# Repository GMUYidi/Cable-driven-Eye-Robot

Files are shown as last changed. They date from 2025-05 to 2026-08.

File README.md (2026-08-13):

# Cable-Driven Eye Robot

Robotic-eye platform for human vision visualization, binocular gaze control,
strabismus simulation, and saccade/foveation experiments.

This repository contains hardware design files, control software, calibration
data, experiment scripts, videos, and analysis tools for a two-eye cable-driven
robotic platform. The current engineering direction is to organize the project
as a full robotics system: hardware, sensing, actuation, kinematics, calibration,
control, telemetry, and visual perception.

## Project Goal

The platform is designed to visualize what a moving eye sees during human-like
eye motion. In particular, the project focuses on:

- Cable-driven robotic eye actuation with 12 Dynamixel motors.
- Binocular yaw, pitch, and torsional eye motion.
- Open-loop inverse-kinematic control from desired gaze angle to motor command.
- IMU-based feedback and pose measurement.
- Dual camera streaming from the eye viewpoint.
- Camera and eye-pose calibration.
- Saccade, fixation, and foveated-perception visualization.
- Data collection for human vision visualization and strabismus diagnosis.

The long-term system objective is:

> From a high-level gaze or saccade command, generate coordinated two-eye motor
> motion, measure the actual eye pose, capture the visual scene from the eye's
> viewpoint, and render what the eye sees during fixation and saccadic motion.

## System Architecture

The project is organized around a layered robotics architecture:

```text
Experiment protocol
  -> gaze target or saccade command
  -> binocular motion planner
  -> eye kinematics and calibration
  -> Dynamixel motor command generation
  -> physical cable-driven eye motion
  -> IMU and camera feedback
  -> synchronized telemetry
  -> foveated visualization and analysis
```

See [ARCHITECTURE.md](ARCHITECTURE.md) for the full architecture document.

## Demo Programs

The runnable demos are thin entry points in [`demos`](demos). They call reusable
modules from [`src/cable_driven_eye_robot`](src/cable_driven_eye_robot), so the
hardware drivers, kinematics, control loops, sensors, and UI are not duplicated
inside large one-file scripts.

```bash
python demos/dashboard_demo.py
python demos/initial_position_tuner.py
python demos/feedback_control.py
python demos/hess_chart_tracking.py
python demos/eye_tracker_replay.py --data-path experiments/eye_tracking/processed_data/<file>.mat
```

- `dashboard_demo.py`: joystick open-loop control, dual IMU pose display, and
  dual ESP32 camera streaming.
- `initial_position_tuner.py`: manual neutral-position calibration for all 12
  Dynamixel motors.
- `feedback_control.py`: joystick target plus IMU feedback correction and CSV
  telemetry logging.
- `hess_chart_tracking.py`: generate Hess-chart gaze targets, track each point
  with IMU feedback, then capture synchronized eye-camera frames when the pose
  reaches tolerance.
- `eye_tracker_replay.py`: replay recorded eye-tracker gaze targets with
  open-loop inverse kinematics and capture synchronized eye-camera frames.

## Repository Structure

```text
.
|-- README.md
|-- ARCHITECTURE.md
|-- requirements.txt
|-- demos/
|   |-- dashboard_demo.py
|   |-- initial_position_tuner.py
|   |-- feedback_control.py
|   |-- hess_chart_tracking.py
|   `-- eye_tracker_replay.py
|-- src/
|   `-- cable_driven_eye_robot/
|       |-- apps/
|       |-- control/
|       |-- data/
|       |-- hardware/
|       |-- input_devices/
|       |-- sensors/
|       |-- ui/
|       |-- config.py
|       `-- kinematics.py
|-- docs/
|   |-- DEMO_RUNBOOK.md
|   |-- HARDWARE.md
|   |-- BILL_OF_MATERIALS.md
|   |-- WIRING.md
|   |-- SOFTWARE_ARCHITECTURE.md
|   |-- CONTROL_AND_CALIBRATION.md
|   |-- REPOSITORY_STRUCTURE.md
|   `-- FILES_NEEDED.md
|-- firmware/
|   `-- esp32_imu_camera/
|-- calibration/
|   `-- camera_intrinsics/
|-- hardware/
|   `-- cad/
|-- experiments/
|   |-- open_loop_accuracy/
|   |-- eye_tracking/
|   `-- binocular_visualization/
|-- media/
|   `-- videos/
`-- tools/
    `-- fusion360/
```

The top-level folders are grouped by responsibility. `src` and `demos` are the
runtime software, `hardware` and `firmware` describe the physical system,
`calibration` stores reusable calibration artifacts, `experiments` stores
research datasets and analysis outputs, `media` stores videos, and `tools`
stores project maintenance scripts.

Representative binocular visualization outputs are included under
[`experiments/binocular_visualization/hess_matched_results`](experiments/binocular_visualization/hess_matched_results).
This result set contains Hess-matched strabismus simulation videos, a healthy
binocular reference video, and the reports/metadata/matrix files needed to
trace each generated video.

## Hardware Summary

- 2 cable-driven robotic eyes.
- 12 ROBOTIS Dynamixel XL330-M288-T actuators, 6 per eye.
- Dynamixel Protocol 2.0 over USB serial.
- ROBOTIS U2D2 and U2D2 Power Hub Board.
- Servo power is injected through the U2D2 Power Hub Board; the currently
  reported adapter is 12 V / 5 A, but the XL330-M288-T bus voltage must be
  verified or regulated before operation.
- Adafruit BNO055 IMU sensing for eye orientation.
- ESP32-S3-CAM OV3660 modules for eye-view video streaming.
- Joystick input for manual gaze control.
- Fusion 360 mechanical design files and exported STL parts.

See [docs/HARDWARE.md](docs/HARDWARE.md),
[docs/BILL_OF_MATERIALS.md](docs/BILL_OF_MATERIALS.md), and
[docs/WIRING.md](docs/WIRING.md) for more detail.

## Software Summary

The control software currently supports:

- Dynamixel sync-write of goal positions.
- Dynamixel sync-read of present positions.
- Extended Position Mode.
- Joystick input through `pygame`.
- Inverse-kinematic cable/muscle pulse computation.
- Listing-law-inspired torsional roll computation.
- IMU serial parsing.
- ESP32 camera stream display through OpenCV.
- CSV logging and offline visualization scripts.

See [docs/CONTROL_AND_CALIBRATION.md](docs/CONTROL_AND_CALIBRATION.md) for the
control and calibration model, and
[docs/SOFTWARE_ARCHITECTURE.md](docs/SOFTWARE_ARCHITECTURE.md) for the modular
software layout.

## Quick Start

Install the Python dependencies:

```bash
pip install -r requirements.txt
```

Run the integrated joystick, IMU, and camera dashboard:

```bash
python demos/dashboard_demo.py
```

Tune the neutral motor positions:

```bash
python demos/initial_position_tuner.py
```

Run the IMU feedback-control demo:

```bash
python demos/feedback_control.py
```

For detailed hardware setup, port configuration, and safety checks, see
[docs/DEMO_RUNBOOK.md](docs/DEMO_RUNBOOK.md).

## Engineering Status

This repository currently contains both research artifacts used to produce
experimental results and a modular runtime for the current robotic-eye demos.

The current refactor direction is to separate:

- Experiment protocols.
- Gaze target generation.
- Saccade and fixation planning.
- Binocular coordination.
- Eye kinematics.
- Dynamixel transport.
- IMU and camera sensing.
- Calibration loading.
- Telemetry logging.
- Foveated visualization.

## Citation / Research Context

This project supports the research work:

**A Novel Cable-driven Eye Robot for Human Vision Visualization and Strabismus
Diagnosis**

The repository includes control code, hardware design files, eye-tracking data,
strabismus simulation resources, and videos related to that work.

## Contact

Yidi Huang
George Mason University
Email: yhuang35@gmu.edu

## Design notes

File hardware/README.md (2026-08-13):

# Hardware

This folder stores hardware design resources for the cable-driven eye robot.

```text
hardware/
  cad/
    fusion360_stl/   exported mechanical parts for fabrication
```

The mechanical design is separated from software so the repository can be read
as a complete robotics system: hardware, firmware, calibration, control, and
experiments.

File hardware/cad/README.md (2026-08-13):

# CAD

Mechanical design files and exported fabrication assets.

```text
hardware/cad/
  fusion360_source/   Fusion 360 source archives, such as .f3d or .f3z
  step/               editable CAD exchange files for solid parts
  stl/                3D-printable mesh exports
  export_inbox/       temporary manual export drop folder
```

For each printable solid part, publish both `.step` and `.stl` when possible.
Mesh-only face-cover parts can be published as `.stl` unless they are converted
to solid BRep bodies in Fusion 360.

See `EXPORT_MANIFEST.md` for the exact printable parts list.

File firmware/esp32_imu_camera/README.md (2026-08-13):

# ESP32 IMU Camera Firmware

This folder contains firmware for the ESP32-S3 camera and BNO055 IMU module.

Main firmware:

```text
IMUcamera.ino
```

The firmware is responsible for:

- Starting the ESP32 camera stream.
- Reading BNO055 IMU data.
- Sending IMU orientation data over serial.
- Joining or creating a Wi-Fi network for camera streaming.

Local Wi-Fi credentials should be stored in `wifi_secrets.h`. That file is
ignored by git and should not be committed.

An example credentials file can be created locally as:

```c
#define WIFI_SSID "your-network"
#define WIFI_PASSWORD "your-password"
```

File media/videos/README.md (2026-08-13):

# Videos

Video assets are grouped by purpose.

```text
videos/
  experiment_videos/              calibration and robot experiment recordings
  simulated_binocular_vision/     synthesized binocular-view videos
  simulated_monocular_vision/     synthesized monocular-view videos
  video_processing/               notebooks and scripts for video generation
```

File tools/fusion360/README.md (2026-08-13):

# Fusion 360 Export Tools

This folder contains helper scripts for exporting selected parts from the
Fusion 360 design.

## Export Workflow

1. Open `headlike robotic eye` in Fusion 360.
2. Save a full source archive manually:
   - `File > Export > Fusion 360 Archive (*.f3z)`
   - Save as `hardware/cad/fusion360_source/headlike_robotic_eye_assembly.f3z`.
3. In Fusion 360, open:
   - `Utilities > Scripts and Add-Ins`.
4. Create or add a Python script and copy the contents of
   `export_headlike_robotic_eye_parts.py`.
5. Run the script while the design is open.
6. Check the generated files in:
   - `hardware/cad/step/`
   - `hardware/cad/stl/`

If a mesh face-cover body cannot be exported by the script, manually right-click
that mesh body and export it as STL using the filenames in
`hardware/cad/EXPORT_MANIFEST.md`.

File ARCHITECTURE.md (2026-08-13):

# Robotic Eye Architecture

## Overview

This project is a robotic-eye control and visualization platform for studying how
the visual scene changes during human-like eye motion. The central goal is not
only to move two artificial eyes, but to make the relationship between gaze,
saccades, fixation, camera input, and foveated perception visible and measurable.

The system should be understood as a layered robotics architecture:

```text
Experiment intent
  -> gaze target / saccade command
  -> binocular eye-motion planner
  -> eye kinematics and calibration
  -> motor command generation
  -> Dynamixel actuator transport
  -> physical eye motion
  -> IMU + camera feedback
  -> synchronized visualization and analysis
```

Current code already contains the main building blocks: joystick-driven gaze
commands, kinematic mapping from yaw/pitch/roll to cable or muscle pulses,
Dynamixel sync-write control, IMU feedback, ESP32 camera streaming, logging, and
offline plotting. This document makes those responsibilities explicit and defines
the architecture needed to support the next research goal: visualizing saccade
and foveation motion from the eye's own viewpoint.

## 1. System Goal

The system goal is to visualize what a moving eye "sees" during saccades and
fixations.

More specifically, the platform should:

- Reproduce gaze shifts that approximate human eye behavior, including fixation,
  fast saccadic motion, post-saccadic settling, and optional pursuit-like motion.
- Capture the camera view from each eye during those movements.
- Estimate the actual eye pose over time from IMU feedback and motor telemetry.
- Show how the scene moves across the image plane during a saccade.
- Provide a foveated view: high-detail information around the gaze center and
  lower-detail peripheral context around it.
- Log commands, measured motion, camera frames, and timing so that each run can
  be replayed, analyzed, and compared.

The research question can be stated as:

> When the robotic eye performs human-like gaze shifts, how does the visual input
> change over time, and how can that change be visualized as foveated perception?

This is different from a simple eye-motion demo. A simple demo asks, "Can the eye
move to a target?" This project asks, "What visual information is available
during that movement, and how does the system represent the difference between
fixation, saccade, and post-saccadic stabilization?"

### Design Priorities

- The visual output matters as much as the mechanical motion.
- The command path and sensing path must be synchronized.
- Gaze trajectories should be repeatable, not only manually controlled.
- Calibration must connect four spaces: motor ticks, eye pose, camera pixels,
  and visual/foveal coordinates.
- The architecture should support both online control and offline replay.

### Non-Goals

- The current system does not need to be a perfect biological model of the human
  retina, eye muscles, or neural control.
- The first version does not need a real-time neural vision model.
- The first version does not need perfect high-speed saccades if the camera,
  IMU, and motor rates limit the measurable bandwidth.

The correct first milestone is a synchronized, measurable, and visually clear
approximation of saccade/fixation/foveation behavior.

## 2. Hardware Overview

The physical platform is a binocular robotic-eye rig with two mechanically
actuated eyes.

### Robotic Eyes

- Two eyes: left and right.
- Each eye is controlled by six actuator channels that approximate extraocular
  muscle actions.
- The modeled muscle order is:
  - MR: medial rectus
  - LR: lateral rectus
  - SR: superior rectus
  - IR: inferior rectus
  - SO: superior oblique
  - IO: inferior oblique
- The eye geometry in the modular controller uses an eyeball radius of 15 mm.
- The kinematic layer converts desired yaw, pitch, and roll into actuator pulse
  differences using insertion points, pulley points, pulse scales, and offsets.

### Actuators

- The current controller targets 12 ROBOTIS Dynamixel XL330-M288-T servos, IDs
  1 through 12.
- IDs 1-6 correspond to the left eye; IDs 7-12 correspond to the right eye.
- Left eye IDs 1-6 map to LR, MR, SR, IR, SO, IO.
- Right eye IDs 7-12 map to MR, LR, SR, IR, SO, IO.
- The controller uses Dynamixel Protocol 2.0 at 1 Mbps.
- The default motor bus is configured as `COM12`.
- Motors are controlled in Extended Position Mode.
- Current code uses sync read for present position and sync write for goal
  position.
- Existing analysis scripts also read present current for estimating torque or
  cable force.
- The current reported power path is an external adapter feeding a U2D2 Power
  Hub Board, while the U2D2 provides USB-to-Dynamixel communication. The adapter
  was reported as 12 V / 5 A, but the actual XL330 bus voltage must be verified
  or regulated before operation.

### Sensors

- IMUs are used to estimate actual eye orientation.
- The IMU model is the Adafruit 9-DOF Absolute Orientation IMU Fusion Breakout -
  BNO055.
- The left IMU is currently mapped to `COM11`.
- The right IMU is currently mapped to `COM6`.
- IMU serial baud rate is 921600.
- The ESP32-S3 camera/IMU firmware uses a BNO055 IMU and currently emits IMU
  data at 20 Hz.

### Cameras

- Each eye can stream from an ESP32-S3-CAM Development Board with an OV3660
  camera, antenna, ESP32-S3 N16R8 module, 16 MB flash, and 8 MB PSRAM.
- Current default camera URLs are:
  - Left camera: `http://192.168.4.1/stream`
  - Right camera: `http://192.168.4.200/stream`
- Camera calibration files are stored under `calibration/camera_intrinsics/`.
- Camera intrinsics and distortion parameters are stored in `.npz` files.

### User Input and Host

- A joystick can provide manual target yaw/pitch commands.
- The host computer runs Python control scripts on Windows.
- Existing scripts use `pygame`, `dynamixel_sdk`, `serial`, `opencv-python`,
  `numpy`, `pandas`, `matplotlib`, `PIL`, and `tkinter`.

### Data Products

- Experiment datasets and analysis outputs are stored under `experiments/`.
- Generated videos are stored under `media/videos/`.
- Reusable calibration artifacts are stored under `calibration/`.

## 3. Software Architecture

The software should be organized around responsibility boundaries, not around
individual experiments. Each layer should have a clear input and output.

```mermaid
flowchart TD
    A["Experiment Protocol"] --> B["Gaze Target Source"]
    B --> C["Saccade and Fixation Planner"]
    C --> D["Binocular Coordination"]
    D --> E["Eye Kinematics"]
    E --> F["Motor Command Builder"]
    F --> G["Dynamixel Transport"]
    G --> H["Physical Robotic Eyes"]
    H --> I["IMU Feedback"]
    H --> J["Eye Cameras"]
    I --> K["Telemetry Logger"]
    J --> K
    F --> K
    K --> L["Replay and Analysis"]
    K --> M["Foveated Visualization"]
```

### Current Implementation Mapping

| Responsibility | Current Files |
| --- | --- |
| Demo entry points | `demos/` |
| Hardware constants and safety limits | `src/cable_driven_eye_robot/config.py` |
| Eye geometry and pulse computation | `src/cable_driven_eye_robot/kinematics.py` |
| Dynamixel sync read/write | `src/cable_driven_eye_robot/hardware/dynamixel.py` |
| Joystick input | `src/cable_driven_eye_robot/input_devices/joystick.py` |
| Shared math helpers | `src/cable_driven_eye_robot/math_utils.py` |
| Combined joystick, IMU, camera dashboard | `src/cable_driven_eye_robot/apps/dashboard_demo.py` |
| IMU feedback control | `src/cable_driven_eye_robot/control/feedback.py` |
| Open-loop control | `src/cable_driven_eye_robot/control/open_loop.py` |
| Camera calibration | `calibration/camera_intrinsics/` |
| ESP32 camera and IMU firmware | `firmware/esp32_imu_camera/IMUcamera.ino` |
| Binocular visualization outputs | `experiments/binocular_visualization/` |
| Offline videos and video processing | `media/videos/` |

### Recommended Target Architecture

The next refactor should separate the project into these conceptual modules:

- `experiment_protocols`: defines repeatable trials such as fixation, single
  saccade, multi-step scan path, pursuit, and replay.
- `gaze_sources`: joystick, scripted target sequence, recorded replay, visual
  target detector, or manual UI.
- `saccade_profiles`: converts target jumps into time-indexed gaze trajectories.
- `binocular_planner`: maps a desired gaze target into left-eye and right-eye
  target poses.
- `eye_kinematics`: converts eye pose into actuator pulse differences.
- `hardware`: owns Dynamixel transport, motor state, torque enable/disable, and
  reset.
- `sensors`: owns IMU readers, camera readers, timestamps, connection status,
  and calibration.
- `foveation`: converts gaze pose and camera frames into foveated visual output.
- `telemetry`: defines the logged data schema and writes synchronized CSV/video
  records.
- `visualization`: live dashboard, offline replay, plots, and presentation
  videos.

This separation matters because the same low-level eye controller should be
usable from a joystick, a scripted saccade experiment, a face/target tracker, or
an offline replay without rewriting motor code.

## 4. Data / Control Flow

The architecture has two important flows: the online control flow and the
offline analysis flow.

### Online Control Flow

```text
Target source
  -> desired gaze target
  -> saccade/fixation planner
  -> desired left/right eye pose
  -> yaw/pitch/roll with Listing roll
  -> muscle pulse differences
  -> absolute Dynamixel goal positions
  -> sync-write motor command
  -> physical eye motion
  -> IMU pose + camera frame + motor telemetry
  -> synchronized display and log
```

For joystick control, the target source is the joystick. For saccade
visualization, the target source should usually be a scripted experiment because
the motion must be repeatable.

### Offline Analysis Flow

```text
CSV telemetry + recorded camera/video
  -> timestamp alignment
  -> command vs actual pose comparison
  -> image-plane motion analysis
  -> foveated render generation
  -> plots, videos, and metrics
```

The offline path is important because camera, IMU, and motor data may run at
different rates. A replay pipeline can interpolate pose and align it with camera
frames more cleanly than the live dashboard can.

### Core Data Contracts

The system should converge around a small set of data types:

#### `GazeTarget`

Represents the high-level visual target.

```text
time_s
target_id
yaw_deg
pitch_deg
vergence_deg, optional
mode: fixation | saccade | pursuit | replay | manual
```

#### `EyePose`

Represents desired or measured eye orientation.

```text
time_s
side: left | right
yaw_deg
pitch_deg
roll_deg
source: command | imu | estimate
valid
```

#### `MotorCommand`

Represents the command sent to the actuator layer.

```text
time_s
motor_id
goal_position_ticks
goal_velocity, optional
goal_current, optional
profile_velocity
profile_acceleration
```

#### `FrameSample`

Represents a camera frame and its timing metadata.

```text
time_s
side: left | right
frame_index
image_width
image_height
camera_url
calibration_id
```

#### `TelemetrySample`

Represents one synchronized row for analysis.

```text
time_s
commanded_left_pose
commanded_right_pose
actual_left_pose
actual_right_pose
motor_positions
motor_currents
camera_frame_indices
experiment_stage
```

The current CSV files already contain many of these fields. The architectural
improvement is to make the schema intentional and consistent across experiments.

## 5. Module Responsibilities

### Experiment Layer

Responsible for deciding what the eye should do.

Examples:

- Hold center fixation for 1 s.
- Saccade 15 deg right in 150 ms.
- Hold fixation after the saccade for 1 s.
- Repeat the same command for five trials.
- Play a predefined scan path over a static scene.

This layer should not know about motor ticks, COM ports, or pulley geometry.

### Gaze Planner

Responsible for turning intent into a time-indexed gaze trajectory.

For saccades, this module should define:

- Start pose.
- End pose.
- Amplitude.
- Duration.
- Peak velocity.
- Acceleration and deceleration shape.
- Optional post-saccadic correction.
- Fixation duration before and after the movement.

The first implementation can use simple profiles such as minimum-jerk,
trapezoidal velocity, or a hand-tuned smooth step. Later versions can implement
human main-sequence-inspired relationships between amplitude, duration, and peak
velocity.

### Binocular Coordination

Responsible for producing left-eye and right-eye pose targets.

For most current experiments, both eyes can receive the same yaw/pitch target.
For more realistic visual behavior, this layer should support:

- Conjugate gaze: both eyes rotate in the same direction.
- Vergence: eyes rotate inward or outward for near/far targets.
- Per-eye calibration offsets.
- Per-eye motion limits.
- Optional suppression of one eye during monocular tests.

### Kinematics Layer

Responsible for mapping eye pose to actuator pulse differences.

Current implementation:

- `compute_listing_roll(x_deg, y_deg)` estimates roll from yaw/pitch.
- `compute_muscle_pulses(...)` rotates insertion points and computes muscle
  length changes relative to pulley points.
- Left and right geometries are built separately because the oblique muscles and
  sign conventions differ between eyes.

This layer should stay independent from Dynamixel transport. Its input should be
eye pose in degrees. Its output should be actuator deltas in ticks or normalized
muscle-length units.

### Actuator / Hardware Layer

Responsible for all Dynamixel communication and motor safety.

Current responsibilities include:

- Open/close the Dynamixel serial port.
- Set Extended Position Mode.
- Configure profile velocity and acceleration.
- Enable or disable torque.
- Sync-read present position.
- Sync-write goal position.
- Reset to calibrated perfect positions.
- Limit large jumps using `max_goal_step`.
- Unwrap multi-turn position targets near the previous goal.

No high-level experiment logic should live in this layer.

### Sensor Layer

Responsible for acquiring measured state.

IMU responsibilities:

- Open the left and right serial ports.
- Parse yaw, pitch, roll, angular velocity, angular acceleration, gyro, and
  linear acceleration when available.
- Apply zero calibration.
- Report connection status and sample age.

Camera responsibilities:

- Open left and right camera streams.
- Decode frames.
- Timestamp each frame.
- Apply camera intrinsics and distortion correction when needed.
- Report frame rate, dropped frames, and connection status.

### Foveation Layer

Responsible for converting camera frames and gaze state into a visualization of
foveated perception.

Initial foveation features:

- Mark the estimated gaze center in the camera image.
- Crop a high-resolution foveal window around the gaze center.
- Blur or downsample peripheral regions.
- Show the image-plane motion path during the saccade.
- Show before-saccade, during-saccade, and after-saccade frames side by side.

More advanced foveation features:

- Gaze-contingent resolution falloff.
- Motion blur or suppression during fast saccade phases.
- Stereo comparison between left and right eye views.
- Stabilized world view reconstructed from eye pose and camera frames.

### Telemetry and Logging Layer

Responsible for making experiments repeatable and analyzable.

Each run should log:

- Experiment name and trial number.
- Commanded gaze target.
- Active trajectory target at each timestep.
- Commanded left/right eye pose.
- Measured left/right IMU pose.
- Pose error.
- Motor goal positions.
- Motor present positions.
- Motor current, when available.
- Camera frame index or video timestamp.
- Loop timing and sensor ages.
- Safety events, resets, and dropped samples.

Logs should be written in a stable schema so that plotting scripts do not need
custom parsing for every experiment.

### Visualization Layer

Responsible for communicating the system behavior.

Live dashboard:

- Show commanded gaze.
- Show measured eye pose.
- Show left/right camera streams.
- Show connection health.
- Show recent errors and safety events.

Offline visualization:

- Plot target vs actual gaze.
- Plot yaw/pitch/roll error.
- Plot saccade duration, overshoot, and settling time.
- Render synchronized camera videos with gaze overlays.
- Render foveated videos showing high-detail center and low-detail periphery.

## 6. Timing and Control Loop

The project has multiple clocks:

- Motor command loop.
- IMU serial sampling.
- Camera frame sampling.
- Joystick polling.
- Visualization refresh.
- CSV/video logging.

These clocks should be treated separately and synchronized through timestamps.

### Current Timing

Existing code shows several timing regimes:

- The modular joystick loop sleeps for 0.002 s, which implies a target loop rate
  up to roughly 500 Hz if communication and computation allow it.
- Some feedback experiments use a 0.05 s loop period, or roughly 20 Hz.
- The ESP32 camera/IMU firmware sets the IMU interval to 50 ms, or 20 Hz.
- Dynamixel transport runs at 1 Mbps.
- Joystick command step limits are currently around 0.08 deg per loop for yaw
  and 0.06 deg per loop for pitch in the modular controller.

### Target Timing Architecture

The control loop should be designed as:

```text
high-rate motor command loop:
    consume latest desired trajectory pose
    compute motor goals
    write goals
    read available motor telemetry
    timestamp command and response

sensor loops:
    read IMU and camera at their own rates
    timestamp each sample immediately
    publish latest valid sample

visualization/logging loop:
    collect latest command, sensor, and frame samples
    align by timestamp
    display and write to disk
```

The motor command loop should not block on camera frame decoding. Camera frame
processing can be slower and asynchronous because foveation visualization is
allowed to lag slightly behind motor control.

### Saccade Trial Phases

A repeatable saccade experiment should use explicit stages:

1. `pre_fixation`: hold the start pose and collect baseline frames.
2. `saccade`: execute the planned rapid gaze transition.
3. `post_fixation`: hold the final pose and measure settling.
4. `return`: optionally return to center or the next start pose.
5. `complete`: stop motion, save logs, and render summary outputs.

Each logged row should include the current stage. This makes plots and videos
much easier to interpret.

### Latency Considerations

The key latency measurements are:

- Command generation to Dynamixel sync-write.
- Sync-write to measured IMU response.
- Camera exposure/readout to host timestamp.
- Camera frame timestamp to visualization display.
- Difference between commanded gaze center and displayed foveal center.

For the foveation goal, camera/pose synchronization is as important as raw motor
speed. A visually impressive demo can still be scientifically weak if the gaze
overlay and camera frame are not time-aligned.

## 7. Calibration Strategy

Calibration is the bridge between hardware motion and meaningful visual output.
The project needs calibration at several levels.

### Motor Zero / Perfect Position Calibration

Purpose:

- Define a repeatable neutral eye pose.
- Make motor commands relative to a known baseline.

Current implementation:

- `perfect_positions` are stored in configuration or experiment scripts.
- `reset_perfect()` sync-writes all motors to calibrated positions.
- The controller then reads present positions and updates the baseline.

Required improvement:

- Store each calibration as a named file with date, rig version, motor IDs, and
  notes.
- Avoid hard-coding different perfect positions across many experiment scripts.
- Record which calibration was used in every CSV log.

### Eye Geometry Calibration

Purpose:

- Map desired yaw/pitch/roll into actuator pulse changes.

Current implementation:

- Geometry is defined by insertion points, pulley points, pulse scales, and
  offsets in `kinematics.py`.

Required improvement:

- Fit pulse scales and offsets from measured motion data.
- Validate the model across a grid of commanded gaze targets.
- Store left and right eye geometry separately.
- Report expected vs measured yaw/pitch/roll error.

### IMU Calibration

Purpose:

- Convert raw IMU orientation into eye pose relative to the neutral pose.

Current implementation:

- Scripts zero IMU pose at startup or on command.
- Some scripts correct roll/camera zero offsets through helper functions.

Required improvement:

- Define a standard IMU coordinate convention.
- Record zero offsets in metadata.
- Track sample age and reject stale IMU data.
- Validate IMU pose against known commanded poses.

### Camera Intrinsic Calibration

Purpose:

- Correct lens distortion and make pixel measurements meaningful.

Current implementation:

- Checkerboard calibration scripts store camera matrix and distortion
  coefficients as `.npz` files.

Required improvement:

- Maintain separate calibration files for left and right cameras.
- Record image resolution and camera module identity.
- Apply undistortion before measuring pixel motion or foveal coordinates.

### Pixel-to-Gaze Calibration

Purpose:

- Map eye pose to image location.
- Identify where the foveal center should appear in each camera frame.

Required approach:

- Command the eye to a grid of yaw/pitch targets.
- Capture camera frames at each target.
- Detect a known visual marker or calibration target.
- Fit a mapping from `(yaw_deg, pitch_deg)` to `(u_px, v_px)`.
- Validate the mapping with held-out target points.

This calibration is essential for foveation. Without it, the system can show a
camera image, but it cannot confidently say where the gaze center is in that
image.

### Temporal Calibration

Purpose:

- Align motor commands, IMU samples, and camera frames.

Required approach:

- Timestamp commands and sensor samples with a common host clock.
- Estimate fixed camera delay if necessary.
- Use step or saccade events to align command onset with measured motion onset.
- Store measured delay values in the experiment metadata.

## 8. Safety Constraints

The system must protect both the hardware and the data quality.

### Motion Limits

Current limits include:

- Maximum yaw/pitch limits for joystick control.
- Deadband around joystick zero.
- Step limits for joystick command changes.
- Maximum pulse magnitude safety check.
- Maximum motor goal step in ticks.

These limits should remain active in all control modes, including scripted
saccades and replay.

### Torque and Reset Safety

The actuator layer should always support:

- Torque enable/disable.
- Reset to perfect positions.
- Reset to initial positions.
- Keyboard stop.
- Shutdown reset and torque disable.

If an exception occurs, the system should attempt to return to a safe state and
disable torque.

### Sensor Health

The system should detect:

- Missing IMU samples.
- Stale IMU data.
- Camera stream disconnects.
- Dropped camera frames.
- Dynamixel communication failures.
- Motor present position unavailable.

Safety behavior should be explicit. For example, if IMU feedback is stale during
a feedback-control trial, the controller should either hold the last safe command
or switch to open-loop mode with a logged warning.

### Mechanical Safety

Because the eyes are cable/muscle-like mechanisms, safety should also consider:

- Cable slack.
- Cable over-tension.
- Pulley interference.
- Unexpected sign inversion in one muscle group.
- Commanded positions outside the calibrated physical range.

The foveation visualization should never require unsafe motion. If the camera
view requires a larger visual angle than the robot can safely reach, the scene or
target arrangement should be changed instead of exceeding motion limits.

## 9. Testing and Success Criteria

Success should be measured at the system level, not only by whether the motors
move.

### Functional Tests

The system should pass these basic checks:

- Opens the Dynamixel port and configures all 12 motors.
- Reads present position from every motor.
- Resets both eyes to calibrated neutral pose.
- Accepts joystick or scripted target input.
- Computes left and right muscle pulses without exceeding safety limits.
- Opens both IMU streams.
- Opens both camera streams.
- Logs a complete CSV file for each experiment run.
- Generates an offline visualization from the logged data.

### Control Performance Metrics

For each saccade trial, measure:

- Commanded amplitude in degrees.
- Actual amplitude in degrees.
- Saccade duration.
- Peak angular velocity.
- Overshoot.
- Settling time.
- Final fixation error.
- RMS tracking error.
- Left/right eye mismatch.

Suggested initial success criteria:

- The system can execute repeatable commanded gaze shifts in yaw and pitch.
- Final fixation error is consistently small enough that the foveal crop lands
  near the intended target.
- Post-saccadic settling is visible and measurable rather than hidden.
- The same scripted trial produces similar target-vs-actual plots across
  repeated runs.

### Foveation / Visualization Metrics

For the main research goal, success means:

- The recorded camera view is synchronized with command and IMU data.
- The gaze center can be overlaid on the image.
- The foveal crop follows the estimated gaze center.
- A video can show pre-saccade, saccade, and post-saccade visual experience.
- The visualization makes clear how peripheral scene content shifts during the
  gaze transition.
- The project can compare commanded foveal center vs measured/estimated foveal
  center.

### Data Quality Metrics

Each experiment should report:

- Average loop period.
- Maximum loop period.
- IMU sample age.
- Camera FPS.
- Dropped frame count.
- Missing motor read count.
- Number of safety limit events.
- Calibration ID used.

### Demonstration-Level Success

A strong final demo should include:

- The physical robotic eyes moving through a scripted saccade sequence.
- Live or recorded left/right camera views.
- A gaze marker showing estimated foveal center.
- A foveated render with high-detail center and lower-detail periphery.
- Target vs actual eye pose plots.
- A short explanation of how the architecture maps from experiment intent to
  motor command to visual output.

## 10. Future Improvements

### Refactor Around Stable Packages

Move one-off experiment scripts toward reusable modules:

- Shared data schema.
- Shared calibration loading.
- Shared motor controller.
- Shared IMU and camera readers.
- Shared logging.
- Shared visualization pipeline.

The existing `src/cable_driven_eye_robot/` package is the starting point for
this direction.

### Add Scripted Saccade Profiles

Implement a dedicated saccade profile generator that supports:

- Step targets.
- Minimum-jerk trajectories.
- Trapezoidal velocity profiles.
- Main-sequence-inspired amplitude/duration selection.
- Randomized trial blocks.
- Replay from CSV.

### Build a Foveated Rendering Pipeline

Add a module that takes camera frames and gaze estimates, then produces:

- Full-resolution center crop.
- Blurred/downsampled periphery.
- Gaze-center overlay.
- Saccade path overlay.
- Time-synchronized output video.

### Improve Closed-Loop Control

The current code includes feedback-control experiments. A future architecture
should turn this into a reusable control layer with:

- Open-loop mode.
- IMU feedback mode.
- Model-based feedforward plus feedback.
- Per-eye gain tuning.
- Anti-windup and saturation handling if integral control is used.
- Explicit fallback behavior when IMU data is stale.

### Improve Synchronization

Add a synchronization layer that:

- Assigns monotonic host timestamps to every command and sensor sample.
- Aligns camera frames to pose estimates.
- Estimates fixed sensor delays.
- Exports synchronized experiment bundles.

### Add Experiment Metadata

Each run should save a metadata file containing:

- Date/time.
- Operator.
- Git or code version if available.
- Hardware configuration.
- Calibration IDs.
- Experiment protocol.
- Safety limits.
- Camera settings.
- IMU settings.

### Expand Visual Science Experiments

Once the basic foveation pipeline works, the platform can support:

- Saccadic suppression visualization.
- Fixation stability and drift analysis.
- Comparison between open-loop and feedback-controlled gaze.
- Binocular vergence experiments.
- Scene stabilization from eye pose.
- Human-like scan-path replay.

## Interview / Portfolio Framing

This project can be described as:

> I built a binocular robotic-eye platform to study and visualize gaze-contingent
> perception. The architecture separates experiment intent, saccade trajectory
> generation, binocular eye kinematics, Dynamixel motor control, IMU/camera
> sensing, telemetry logging, and foveated visualization. This allows the same
> hardware to run joystick demos, scripted saccade experiments, closed-loop IMU
> feedback tests, and offline replay analysis.

The important architectural point is that the project is not just a collection
of motor scripts. It is a robotics system with a clear path from high-level gaze
intent to physical motion and finally to visual evidence of what the moving eye
sees.

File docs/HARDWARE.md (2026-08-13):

# Hardware Architecture

This document describes the current hardware architecture of the cable-driven
binocular robotic-eye platform. The goal is to make the physical system
understandable and reproducible from the repository.

## Physical System

The platform is a binocular cable-driven robotic-eye system. Each eye is driven
by six actuator channels inspired by the six human extraocular muscles:

- LR: lateral rectus
- MR: medial rectus
- SR: superior rectus
- IR: inferior rectus
- SO: superior oblique
- IO: inferior oblique

The full platform uses 12 Dynamixel servos total, with 6 servos per eye.

## Actuation

The current actuator configuration is:

```text
Servo model:       ROBOTIS Dynamixel XL330-M288-T
Servo count:       12
Servos per eye:    6
Protocol:          Dynamixel Protocol 2.0
Host interface:    ROBOTIS U2D2
Power interface:   ROBOTIS U2D2 Power Hub Board
External supply:   reported as 12 V / 5 A DC adapter; verify/regulate bus voltage
Control mode:      Extended Position Mode for the current demos
```

The current Python demos command the motors through synchronized Dynamixel
position writes. The 12 servos are treated as one coordinated actuator group so
that all cable commands are updated together.

## Motor ID and Muscle Map

This is the current motor-to-muscle mapping used by the physical robot.

| Motor ID | Eye | Muscle / Cable |
| --- | --- | --- |
| 1 | Left | LR |
| 2 | Left | MR |
| 3 | Left | SR |
| 4 | Left | IR |
| 5 | Left | SO |
| 6 | Left | IO |
| 7 | Right | MR |
| 8 | Right | LR |
| 9 | Right | SR |
| 10 | Right | IR |
| 11 | Right | SO |
| 12 | Right | IO |

Note that the left and right horizontal rectus ordering is mirrored:

```text
Left eye IDs 1-2:   LR, MR
Right eye IDs 7-8:  MR, LR
```

This matters for both cable routing and sign conventions in the kinematic model.

## Power and Communication Chain

The Dynamixel bus uses the U2D2 for communication and the U2D2 Power Hub Board
for servo power injection.

```text
Computer USB
   |
   | USB: communication + power for U2D2 electronics
   v
U2D2
   |
   | TTL / RS485 Dynamixel communication
   v
U2D2 Power Hub Board <---- external supply
                             reported: 12 V / 5 A adapter
                             required: verify/regulate for XL330 bus voltage
   |
   | communication + servo power
   v
Dynamixel XL330-M288-T servos
```

Important electrical notes:

- The computer USB powers the U2D2 communication interface.
- The external supply powers the Dynamixel servos through the Power Hub Board.
- The Power Hub Board carries both Dynamixel communication and servo power to
  the bus.
- Always confirm the supply polarity and voltage before connecting the motors.
- The XL330-M288-T operating voltage must be checked against the official
  ROBOTIS specification before applying power. Do not assume the Power Hub Board
  regulates the input voltage unless that has been verified on the physical
  setup.

## Sensing

The current sensing stack includes:

- Left eye IMU.
- Right eye IMU.
- Left eye camera.
- Right eye camera.
- Dynamixel present-position feedback.
- Optional Dynamixel present-current feedback in analysis scripts.

## IMU

The IMU module is:

```text
Adafruit 9-DOF Absolute Orientation IMU Fusion Breakout - BNO055
```

The BNO055 is used to measure eye orientation, including yaw, pitch, and roll.
The current demo software reads IMU data over serial and uses it for live
visualization and feedback-control experiments.

## Camera

The eye camera module is:

```text
ESP32-S3-CAM Development Board with OV3660 Camera + Antenna
ESP32-S3 N16R8 module, 16 MB flash, 8 MB PSRAM
```

The camera provides the robot-eye viewpoint for visualization. In the current
dashboard, the host computer reads left and right camera streams over Wi-Fi.

The ESP32-S3 camera firmware is located at:

```text
firmware/esp32_imu_camera/IMUcamera.ino
```

The firmware includes:

- ESP32 camera streaming.
- BNO055 IMU communication.
- Serial IMU output.
- Wi-Fi access point or client configuration.

Do not commit local Wi-Fi credentials. Put credentials in `wifi_secrets.h`,
which is ignored by git.

## Mechanical Design Files

Existing mechanical files are stored in:

```text
hardware/cad/fusion360_stl/
```

This folder includes STL exports for the eyeball, supports, base parts, spools,
and related mechanical pieces.

## Documentation Still Needed

To make the hardware fully reproducible, add the following:

- Front, side, rear, and cable-routing photos of the robot.
- Motor ID labels visible on the physical robot.
- Cable routing diagram for all 12 actuator channels.
- Wiring diagram photo or schematic.
- Assembly screenshots from Fusion 360.
- Final bill of materials with purchase links.

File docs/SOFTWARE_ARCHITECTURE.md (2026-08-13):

# Software Architecture

The repository separates runnable demo entry points from reusable robotics
modules.

1. `demos/` contains the small scripts a user runs from the command line.
2. `src/cable_driven_eye_robot/` contains the reusable implementation.

This keeps the project readable: demo files describe what is being run, while
the package owns the hardware drivers, sensing, kinematics, control, UI, and
calibration-related logic.

## Modular Package Layout

```text
src/cable_driven_eye_robot/
  config.py
  math_utils.py
  kinematics.py
  hardware/
    dynamixel.py
  input_devices/
    joystick.py
  data/
    eye_tracker.py
    hess_chart.py
  sensors/
    imu.py
    camera.py
    frame_capture.py
  control/
    open_loop.py
    feedback.py
  ui/
    state.py
    dashboard.py
  apps/
    dashboard_demo.py
    initial_position_tuner.py
    feedback_control.py
    hess_chart_tracking.py
    eye_tracker_replay.py
```

## Responsibility Boundaries

### Configuration

`config.py` centralizes motor IDs, motor-to-muscle mapping, Dynamixel settings,
joystick axes, IMU ports, camera URLs, safety limits, and feedback gains.

### Hardware

`hardware/dynamixel.py` owns all Dynamixel communication: port setup, Extended
Position Mode, profile velocity/acceleration, torque enable/disable, sync-read,
sync-write, startup baseline capture, and reset.

Application code should not directly call `PacketHandler` or `GroupSyncWrite`.

### Input

`input_devices/joystick.py` owns joystick setup and target reading. It converts
right-stick input into bounded yaw/pitch targets.

### Data

`data/eye_tracker.py` loads recorded eye-tracker `.mat` files and converts them
into left/right `EyePose` targets for replay experiments.

`data/hess_chart.py` generates scripted Hess-style gaze targets. It supports a
9-point center/cardinal/diagonal pattern and configurable yaw/pitch grids.

### Kinematics

`kinematics.py` owns the eye geometry and inverse kinematics. It computes
Listing-style roll, cable/muscle length changes, and the final 12-motor pulse
vector.

### Sensors

`sensors/imu.py` parses BNO055 serial data, applies zero calibration, and
publishes the latest pose sample.

`sensors/camera.py` opens ESP32-S3-CAM streams, reconnects after dropped frames,
and publishes the latest camera frame.

`sensors/frame_capture.py` captures still frames from ESP32-S3 camera streams
for scripted experiments.

### Control

`control/open_loop.py` implements the current joystick demo behavior:

```text
joystick right stick
  -> yaw/pitch target
  -> smoothed command
  -> Listing-style roll
  -> inverse kinematics
  -> 12 motor pulse commands
  -> Dynamixel sync-write
```

`control/feedback.py` implements a bounded PD-style correction around open-loop
inverse kinematics:

```text
open-loop IK motor command
  + IMU pose error correction
  -> corrected motor command
```

The feedback layer should be treated as a tunable baseline. The open-loop model
remains the main command, and feedback adds a bounded correction.

`apps/eye_tracker_replay.py` uses the same inverse-kinematic model to replay
recorded eye-tracker targets and capture camera frames after each commanded
pose settles. It is intentionally open-loop and should not be confused with the
IMU feedback controller.

`apps/hess_chart_tracking.py` is the scripted closed-loop experiment. It
generates Hess-chart targets, commands IK feedforward plus IMU feedback, waits
for consecutive in-tolerance pose samples, captures left/right camera frames,
and logs summary plus loop-level telemetry.

### UI

`ui/state.py` stores the latest command, IMU, camera, and log state.

`ui/dashboard.py` renders the Tkinter dashboard. The UI does not directly
command motors.

## Demo Entrypoints

Run from the repository root:

```bash
python demos/dashboard_demo.py
python demos/initial_position_tuner.py
python demos/feedback_control.py
python demos/hess_chart_tracking.py
python demos/eye_tracker_replay.py --data-path experiments/eye_tracking/processed_data/<file>.mat
```

The dashboard supports debug modes:

```bash
python demos/dashboard_demo.py --no-motors
python demos/dashboard_demo.py --no-serial
python demos/dashboard_demo.py --no-cameras
```

## Migration Strategy

The project should migrate in stages:

1. Keep demo entry points small and readable.
2. Put shared behavior into package modules.
3. Test each demo entry point on hardware.
4. Move new behavior into `src/cable_driven_eye_robot/` instead of copying code
   between scripts.
5. Keep research data, videos, and CAD files in documented folders.

This makes the repository easier to understand and easier to extend without
turning each new experiment into another large standalone script.

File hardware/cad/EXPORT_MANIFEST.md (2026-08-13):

# CAD Export Manifest

This manifest defines the CAD files that should be exported from the Fusion 360
design `headlike robotic eye` for public release and fabrication.

## Required Printable Parts

| Output name | Fusion 360 source name | Quantity | Export formats |
| --- | --- | ---: | --- |
| `eyeball_r1` | `eyeball_r1` | 1 | STEP, STL |
| `eyeball_r2` | `eyeball_r2` | 1 | STEP, STL |
| `front_eye_support_right` | `front eye support of right eye` | 1 | STEP, STL |
| `main_base_right_eye` | `Main base of right eye (1)` | 1 | STEP, STL |
| `support4` | `support4` | 1 | STEP, STL |
| `main_base_left_eye` | `Main base of left eye` | 1 | STEP, STL |
| `eyeball_l1` | `eyeball_l1` | 1 | STEP, STL |
| `eyeball_l2` | `eyeball_l2` | 1 | STEP, STL |
| `front_eye_support_left` | `front eye support of left eye` | 1 | STEP, STL |
| `connection` | `connection` | 1 | STEP, STL |
| `servo_spool_1` | `servo spool 1` | 12 | STEP, STL |
| `servo_spool_2` | `servo spool 2` | 12 | STEP, STL |
| `face_cover_upper` | `eyeglass` -> `MeshBody 1` / `网格实体1` | 1 | STL |
| `face_cover_lower` | `topmouth` -> `MeshBody 1` / `网格实体1` | 1 | STL |

## Optional Assembly Exports

Export these manually from Fusion 360 if possible:

- `headlike_robotic_eye_assembly.f3z`
- `headlike_robotic_eye_assembly.step`

Place them in:

```text
hardware/cad/fusion360_source/
hardware/cad/step/
```

## Notes

- STEP is the preferred editable CAD exchange format for solid parts.
- STL is the preferred fabrication format for 3D printing.
- Mesh bodies generally export cleanly as STL. If a mesh body must also be
  edited as CAD, convert it to a solid BRep in Fusion 360 first, then export
  STEP.

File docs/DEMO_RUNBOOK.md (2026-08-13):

# Demo Runbook

This document describes how to run the current robotic-eye demonstrations in a
repeatable and safe way.

## Demo Goals

The demo should show that the system is more than a motor script:

- A joystick command becomes a desired binocular gaze target.
- Gaze target is converted into cable/muscle actuator commands.
- Commands are sent to 12 Dynamixel motors.
- IMU feedback reports actual eye orientation.
- Eye-mounted cameras show the scene from the robot's viewpoint.
- The dashboard visualizes motion, sensing, and camera data together.

## Hardware Checklist

Before running the demo:

- The U2D2 is connected to the computer over USB.
- The U2D2 Power Hub Board is connected to the Dynamixel bus.
- The external adapter is connected to the Power Hub Board.
- The actual Dynamixel bus voltage has been measured and confirmed safe for the
  XL330-M288-T servos.
- All 12 Dynamixel IDs are available on the bus.
- Left and right IMUs are connected.
- Left and right ESP32 camera streams are powered.
- Joystick is connected.
- Cables do not bind at the expected motion range.
- The eyes are near the calibrated neutral pose.

## Default Port and Stream Configuration

Current default values used by the newer demo code:

```text
Servo model:    Dynamixel XL330-M288-T
Motor IDs:      1-12
Power path:     external adapter -> U2D2 Power Hub -> Dynamixel bus
Power note:     reported adapter is 12 V / 5 A; verify/regulate bus voltage
Dynamixel bus: COM12
Left IMU:      COM11
Right IMU:     COM6
IMU baud:      921600
Left camera:   http://192.168.4.1/stream
Right camera:  http://192.168.4.200/stream
```

If hardware ports differ on another computer, override them from the command
line or update `src/cable_driven_eye_robot/config.py`.

## Python Environment

Install dependencies:

```bash
pip install -r requirements.txt
```

Important packages:

- `dynamixel-sdk`
- `pygame`
- `pyserial`
- `opencv-python`
- `pillow`
- `numpy`
- `pandas`
- `matplotlib`
- `scipy`

## Demo 1: Integrated Joystick, IMU, and Camera Dashboard

Run:

```bash
python demos/dashboard_demo.py
```

What to show:

- Right joystick movement drives horizontal and vertical gaze.
- Both eyes move together through open-loop inverse kinematics.
- Joystick command and physical eye motion.
- Left and right IMU eye-pose visualization.
- Left and right camera streams.
- Connection status and live dashboard behavior.
- The mechanism returns to neutral when the program exits.
- Safety clamps prevent very large commands.

Debug modes:

```bash
python demos/dashboard_demo.py --no-motors
python demos/dashboard_demo.py --no-serial
python demos/dashboard_demo.py --no-cameras
```

Use `--no-motors` when testing the UI without moving hardware.

## Demo 2: Manual Initial Position Tuning

Run:

```bash
python demos/initial_position_tuner.py
```

Purpose:

- Select one motor at a time with the controller buttons.
- Jog that motor with the right stick.
- Print the final 12 present positions.
- Use those positions as candidate neutral or `perfect_positions` values.

## Demo 3: Joystick IMU Feedback Control

Run:

```bash
python demos/feedback_control.py
```

Control concept:

```text
joystick target
  -> open-loop inverse-kinematic feedforward
  -> IMU yaw/pitch/roll feedback
  -> bounded PD-style motor correction
  -> corrected Dynamixel command
```

This feedback controller is a tunable baseline. Gains and signs should be
validated on hardware before treating it as final.

## Demo 4: Eye-Tracker Replay and Camera Capture

Run:

```bash
python demos/eye_tracker_replay.py --data-path experiments/eye_tracking/processed_data/<file>.mat
```

Purpose:

- Load recorded eye-tracker gaze targets from a MATLAB `.mat` file.
- Convert each left/right target angle into motor commands using the inverse
  kinematic model.
- Wait briefly for the commanded pose to settle.
- Capture one left and one right camera frame for each target.
- Save an experiment log under `outputs/eye_tracker_replay/`.

This demo is open-loop. It replays recorded gaze targets through the kinematic
model and does not apply PD feedback correction from IMU pose error.

## Demo 5: Hess-Chart IMU Feedback Tracking

Run the default 9-point target sequence:

```bash
python demos/hess_chart_tracking.py
```

Run a custom yaw/pitch grid:

```bash
python demos/hess_chart_tracking.py --pattern grid --yaw-points=-10,-5,0,5,10 --pitch-points=-8,0,8
```

Purpose:

- Generate a scripted Hess-style gaze sequence.
- Convert each target into inverse-kinematic feedforward motor commands.
- Use left/right IMU pose error to add bounded PD correction.
- Require several consecutive in-tolerance IMU samples before accepting a
  target.
- Capture synchronized left/right eye-camera frames after the target is reached.
- Save target-level and loop-level telemetry under `outputs/hess_chart_tracking/`.

Dry run without moving hardware or opening cameras:

```bash
python demos/hess_chart_tracking.py --no-motors --no-cameras --no-imu
```

This is the cleaner replacement for the older monolithic "open/close loop"
experiment script: the target sequence, feedback controller, hardware driver,
IMU reader, camera capture, and telemetry logging are now separate modules.

## Safety Procedure

Before motion:

- Keep one hand near the motor power switch.
- Confirm the Dynamixel bus is powered through the U2D2 Power Hub Board.
- Confirm the measured bus voltage is safe for XL330-M288-T before enabling
  torque.
- Confirm joystick axes are centered.
- Confirm the robot starts near neutral.
- Start with small motions.

During motion:

- Watch for cable slack, over-tension, or mechanical contact.
- Stop if any motor moves in the wrong direction.
- Stop if the camera or IMU cable interferes with the eye.

After motion:

- Return to neutral.
- Disable motor torque.
- Save any logs or videos from the run.

## Demo Narrative for Interviews

A concise explanation:

> The demo starts from a high-level gaze command, generated by a joystick. The
> controller maps that command into binocular yaw, pitch, and roll, computes the
> corresponding cable/muscle actuator changes, and sends synchronized commands to
> 12 Dynamixel motors. IMUs measure the actual eye pose, while eye-mounted
> cameras stream the visual scene. This lets the same platform support hardware
> motion demos, closed-loop control experiments, and future saccade/foveation
> visualization.

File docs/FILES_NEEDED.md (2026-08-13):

# Files and Information Needed

This checklist tracks what is already documented and what still needs to be
added so that another person can understand and reproduce the project.

## Already Documented

The following information has been added to the repository:

- Main actuator model: ROBOTIS Dynamixel XL330-M288-T.
- Actuator count: 12 total, 6 per eye.
- Power architecture: U2D2 + U2D2 Power Hub Board.
- Reported servo power adapter: external 12 V / 5 A DC adapter.
- IMU model: Adafruit 9-DOF Absolute Orientation IMU Fusion Breakout - BNO055.
- Camera model: ESP32-S3-CAM Development Board with OV3660 Camera + Antenna,
  ESP32-S3 N16R8 module, 16 MB flash, 8 MB PSRAM.
- Current motor-to-muscle map:
  - Left eye IDs 1-6: LR, MR, SR, IR, SO, IO.
  - Right eye IDs 7-12: MR, LR, SR, IR, SO, IO.

## Highest Priority Still Needed

1. Clear photos of the physical robot.
   - Front view.
   - Side view.
   - Back/wiring view.
   - Close-up of one eye and cable routing.

2. A short demo video.
   - Joystick moving both eyes.
   - Dashboard showing IMU and camera streams.
   - Optional split-screen of physical robot and software dashboard.

3. Wiring evidence.
   - Photo of computer -> U2D2 -> Power Hub -> Dynamixel bus.
   - Photo of the 12 V / 5 A adapter connected to the Power Hub.
   - Measured voltage at the Dynamixel connector after the Power Hub/regulator.
   - Photo of left/right IMU mounting.
   - Photo of left/right ESP32-S3-CAM mounting.

4. Current known-good software settings.
   - Dynamixel port used by the main demo.
   - Dynamixel baudrate used by the main demo.
   - Left and right IMU serial ports.
   - Left and right camera stream URLs.

5. Neutral calibration values.
   - Current final `perfect_positions`.
   - How those values were measured.
   - Date and hardware configuration.

## Important for Engineering Credibility

6. Mechanical assembly documentation.
   - Fusion 360 screenshot.
   - Exploded view if available.
   - Cable routing path.
   - Spool radius or cable attachment geometry.

7. Calibration experiment data.
   - Target yaw/pitch grid.
   - Actual IMU yaw/pitch/roll.
   - Motor positions.
   - Camera frames if available.

8. Representative plots.
   - Target vs actual yaw.
   - Target vs actual pitch.
   - Error over time.
   - Open-loop vs feedback comparison.

9. Foveation demo material.
   - Final Hess-matched strabismus videos have been added under
     `experiments/binocular_visualization/hess_matched_results/`.
   - Healthy-reference binocular video has been added for comparison.
   - Remaining future need: connect these videos back to the exact generation
     scripts and document the full regeneration command sequence.

## Useful but Optional

10. Purchase links for each part in the bill of materials.
11. Exact screw/fastener list.
12. Cable material, diameter, and length.
13. 3D print settings.
14. CAD source files in addition to STL exports.
15. Troubleshooting notes.
16. Known limitations.
17. A one-page system diagram image for the README.

## Please Do Not Commit

- Wi-Fi passwords.
- Private participant information.
- Raw data that should not be public.
- Local machine-specific paths unless they are clearly marked as examples.
- Very large videos unless they are intentionally part of the public repository.

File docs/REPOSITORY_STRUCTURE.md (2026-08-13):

# Repository Structure

This repository contains the robotic-eye demo software, documentation, firmware,
calibration files, and research artifacts.

## Top-Level Layout

```text
README.md
ARCHITECTURE.md
requirements.txt
demos/
src/cable_driven_eye_robot/
docs/
firmware/
hardware/
calibration/
experiments/
media/
tools/
```

These folders are grouped by responsibility so a reviewer can quickly separate
robot runtime code from hardware files, calibration assets, experiment results,
and project maintenance tools.

## Folder Responsibilities

```text
demos/                         runnable demo entry points
src/cable_driven_eye_robot/     reusable Python robotics package
docs/                           architecture, hardware, wiring, runbook
firmware/                       ESP32-S3 camera and IMU firmware
hardware/cad/                   mechanical design and STL files
calibration/camera_intrinsics/  camera matrix and distortion files
experiments/open_loop_accuracy/ open-loop IK accuracy dataset
experiments/eye_tracking/       participant eye-tracking data
experiments/binocular_visualization/
                                homography, strabismus, and binocular visualization outputs
media/videos/                   experiment and synthesized vision videos
tools/fusion360/                Fusion 360 CAD export helpers
```

## Recommended Future Additions

Long term, the project should move toward:

```text
src/cable_driven_eye_robot/
  hardware/
  kinematics/
  control/
  sensors/
  calibration/
  telemetry/
  visualization/
  experiments/

demos/
  dashboard_demo.py
  initial_position_tuner.py
  feedback_control.py
  hess_chart_tracking.py
  eye_tracker_replay.py
  scripted_saccade/
  foveated_view/

docs/
  architecture
  hardware
  bill of materials
  wiring
  software architecture
  control
  calibration
  experiments
  troubleshooting
```

The current structure gives reviewers a clean entry point while leaving room for
future experiments such as scripted saccades and foveated-view rendering.

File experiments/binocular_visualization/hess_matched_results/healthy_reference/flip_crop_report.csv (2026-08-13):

frame | source_width | source_height | crop_left | crop_top | crop_right | crop_bottom | crop_width | crop_height | invalid_pixels_inside_crop | output_width | output_height
frame_0000.jpg | 1668 | 1297 | 22 | 37 | 1668 | 1172 | 1646 | 1135 | 0 | 1646 | 1135
frame_0002.jpg | 1668 | 1297 | 20 | 35 | 1668 | 1169 | 1648 | 1134 | 0 | 1648 | 1134
frame_0004.jpg | 1668 | 1297 | 19 | 35 | 1668 | 1169 | 1649 | 1134 | 0 | 1649 | 1134
frame_0006.jpg | 1668 | 1297 | 20 | 35 | 1668 | 1170 | 1648 | 1135 | 0 | 1648 | 1135
frame_0008.jpg | 1668 | 1297 | 20 | 34 | 1668 | 1169 | 1648 | 1135 | 0 | 1648 | 1135
frame_0010.jpg | 1668 | 1297 | 20 | 35 | 1668 | 1170 | 1648 | 1135 | 0 | 1648 | 1135
frame_0012.jpg | 1668 | 1297 | 20 | 34 | 1668 | 1169 | 1648 | 1135 | 0 | 1648 | 1135
frame_0014.jpg | 1668 | 1297 | 21 | 34 | 1668 | 1169 | 1647 | 1135 | 0 | 1647 | 1135
frame_0016.jpg | 1668 | 1297 | 20 | 36 | 1668 | 1171 | 1648 | 1135 | 0 | 1648 | 1135
frame_0018.jpg | 1668 | 1297 | 15 | 41 | 1668 | 1175 | 1653 | 1134 | 0 | 1653 | 1134
frame_0020.jpg | 1668 | 1297 | 16 | 40 | 1668 | 1175 | 1652 | 1135 | 0 | 1652 | 1135
frame_0022.jpg | 1668 | 1297 | 16 | 39 | 1668 | 1174 | 1652 | 1135 | 0 | 1652 | 1135
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

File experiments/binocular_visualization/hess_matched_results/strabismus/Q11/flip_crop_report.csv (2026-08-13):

frame | source_width | source_height | crop_left | crop_top | crop_right | crop_bottom | crop_width | crop_height | invalid_pixels_inside_crop | output_width | output_height
frame_0000.jpg | 1668 | 1297 | 41 | 52 | 1668 | 1177 | 1627 | 1125 | 0 | 1627 | 1125
frame_0002.jpg | 1668 | 1297 | 37 | 52 | 1668 | 1177 | 1631 | 1125 | 0 | 1631 | 1125
frame_0004.jpg | 1668 | 1297 | 41 | 44 | 1668 | 1181 | 1627 | 1137 | 0 | 1627 | 1137
frame_0006.jpg | 1668 | 1297 | 47 | 37 | 1668 | 1174 | 1621 | 1137 | 0 | 1621 | 1137
frame_0008.jpg | 1668 | 1297 | 47 | 37 | 1668 | 1174 | 1621 | 1137 | 0 | 1621 | 1137
frame_0010.jpg | 1668 | 1297 | 74 | 31 | 1668 | 1227 | 1594 | 1196 | 0 | 1594 | 1196
frame_0012.jpg | 1668 | 1297 | 43 | 38 | 1668 | 1175 | 1625 | 1137 | 0 | 1625 | 1137
frame_0014.jpg | 1668 | 1297 | 42 | 38 | 1668 | 1174 | 1626 | 1136 | 0 | 1626 | 1136
frame_0016.jpg | 1668 | 1297 | 43 | 38 | 1668 | 1175 | 1625 | 1137 | 0 | 1625 | 1137
frame_0018.jpg | 1668 | 1297 | 43 | 38 | 1668 | 1175 | 1625 | 1137 | 0 | 1625 | 1137
frame_0020.jpg | 1668 | 1297 | 42 | 38 | 1668 | 1174 | 1626 | 1136 | 0 | 1626 | 1136
frame_0022.jpg | 1668 | 1297 | 42 | 38 | 1668 | 1175 | 1626 | 1137 | 0 | 1626 | 1137
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

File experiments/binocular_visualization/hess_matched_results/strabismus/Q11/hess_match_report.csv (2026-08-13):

frame | stem | frame_index | left_path | right_path | base_stitched_path | output_path | output_width | output_height | hess_residual_x | hess_residual_y | target_dx | target_dy | measured_dx | measured_dy | correction_dx | correction_dy | correction_norm | left_translation_x | left_translation_y | right_translation_x | right_translation_y | selected_left_rank | selected_right_rank | selected_pair_error_to_target | selected_left_x | selected_left_y | selected_right_x | selected_right_y | left_candidate_count | right_candidate_count | canvas_left_h_11 | canvas_left_h_12 | canvas_left_h_13 | canvas_left_h_21 | canvas_left_h_22 | canvas_left_h_23 | canvas_left_h_31 | canvas_left_h_32 | canvas_left_h_33 | canvas_right_h_11 | canvas_right_h_12 | canvas_right_h_13 | canvas_right_h_21 | canvas_right_h_22 | canvas_right_h_23 | canvas_right_h_31 | canvas_right_h_32 | canvas_right_h_33
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

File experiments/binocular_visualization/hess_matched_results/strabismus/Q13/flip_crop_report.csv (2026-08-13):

frame | source_width | source_height | crop_left | crop_top | crop_right | crop_bottom | crop_width | crop_height | invalid_pixels_inside_crop | output_width | output_height
frame_0000.jpg | 1668 | 1297 | 87 | 0 | 1668 | 1181 | 1581 | 1181 | 0 | 1581 | 1181
frame_0002.jpg | 1668 | 1297 | 89 | 0 | 1668 | 1181 | 1579 | 1181 | 0 | 1579 | 1181
frame_0004.jpg | 1668 | 1297 | 86 | 0 | 1668 | 1187 | 1582 | 1187 | 0 | 1582 | 1187
frame_0006.jpg | 1668 | 1297 | 86 | 0 | 1668 | 1187 | 1582 | 1187 | 0 | 1582 | 1187
frame_0008.jpg | 1668 | 1297 | 85 | 0 | 1668 | 1185 | 1583 | 1185 | 0 | 1583 | 1185
frame_0010.jpg | 1668 | 1297 | 83 | 0 | 1668 | 1183 | 1585 | 1183 | 0 | 1585 | 1183
frame_0012.jpg | 1668 | 1297 | 82 | 0 | 1668 | 1181 | 1586 | 1181 | 0 | 1586 | 1181
frame_0014.jpg | 1668 | 1297 | 82 | 0 | 1668 | 1181 | 1586 | 1181 | 0 | 1586 | 1181
frame_0016.jpg | 1668 | 1297 | 82 | 0 | 1668 | 1181 | 1586 | 1181 | 0 | 1586 | 1181
frame_0018.jpg | 1668 | 1297 | 82 | 0 | 1668 | 1181 | 1586 | 1181 | 0 | 1586 | 1181
frame_0020.jpg | 1668 | 1297 | 84 | 0 | 1668 | 1180 | 1584 | 1180 | 0 | 1584 | 1180
frame_0022.jpg | 1668 | 1297 | 83 | 0 | 1668 | 1180 | 1585 | 1180 | 0 | 1585 | 1180
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

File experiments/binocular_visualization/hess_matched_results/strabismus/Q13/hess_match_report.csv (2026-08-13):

frame | stem | frame_index | left_path | right_path | base_stitched_path | output_path | output_width | output_height | hess_residual_x | hess_residual_y | target_dx | target_dy | measured_dx | measured_dy | correction_dx | correction_dy | correction_norm | left_translation_x | left_translation_y | right_translation_x | right_translation_y | selected_left_rank | selected_right_rank | selected_pair_error_to_target | selected_left_x | selected_left_y | selected_right_x | selected_right_y | left_candidate_count | right_candidate_count | canvas_left_h_11 | canvas_left_h_12 | canvas_left_h_13 | canvas_left_h_21 | canvas_left_h_22 | canvas_left_h_23 | canvas_left_h_31 | canvas_left_h_32 | canvas_left_h_33 | canvas_right_h_11 | canvas_right_h_12 | canvas_right_h_13 | canvas_right_h_21 | canvas_right_h_22 | canvas_right_h_23 | canvas_right_h_31 | canvas_right_h_32 | canvas_right_h_33
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

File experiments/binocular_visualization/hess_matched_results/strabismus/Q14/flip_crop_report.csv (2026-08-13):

frame | source_width | source_height | crop_left | crop_top | crop_right | crop_bottom | crop_width | crop_height | invalid_pixels_inside_crop | output_width | output_height
frame_0000.jpg | 1750 | 1238 | 125 | 0 | 1721 | 1175 | 1596 | 1175 | 0 | 1596 | 1175
frame_0002.jpg | 1734 | 1236 | 113 | 0 | 1709 | 1179 | 1596 | 1179 | 0 | 1596 | 1179
frame_0004.jpg | 1737 | 1237 | 113 | 0 | 1709 | 1183 | 1596 | 1183 | 0 | 1596 | 1183
frame_0006.jpg | 1736 | 1236 | 110 | 0 | 1706 | 1188 | 1596 | 1188 | 0 | 1596 | 1188
frame_0008.jpg | 1736 | 1237 | 111 | 0 | 1707 | 1188 | 1596 | 1188 | 0 | 1596 | 1188
frame_0010.jpg | 1735 | 1236 | 112 | 0 | 1708 | 1188 | 1596 | 1188 | 0 | 1596 | 1188
frame_0012.jpg | 1739 | 1236 | 121 | 0 | 1717 | 1186 | 1596 | 1186 | 0 | 1596 | 1186
frame_0014.jpg | 1742 | 1237 | 122 | 0 | 1718 | 1187 | 1596 | 1187 | 0 | 1596 | 1187
frame_0016.jpg | 1761 | 1251 | 136 | 0 | 1732 | 1193 | 1596 | 1193 | 0 | 1596 | 1193
frame_0018.jpg | 1762 | 1249 | 136 | 0 | 1732 | 1193 | 1596 | 1193 | 0 | 1596 | 1193
frame_0020.jpg | 1765 | 1251 | 139 | 0 | 1735 | 1193 | 1596 | 1193 | 0 | 1596 | 1193
frame_0022.jpg | 1765 | 1251 | 140 | 0 | 1736 | 1193 | 1596 | 1193 | 0 | 1596 | 1193
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

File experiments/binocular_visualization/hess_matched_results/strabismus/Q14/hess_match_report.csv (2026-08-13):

frame | stem | frame_index | left_path | right_path | base_stitched_path | output_path | output_width | output_height | hess_residual_x | hess_residual_y | target_dx | target_dy | measured_dx | measured_dy | raw_correction_dx | raw_correction_dy | raw_correction_norm | correction_dx | correction_dy | correction_norm | correction_interpolated | left_translation_x | left_translation_y | right_translation_x | right_translation_y | selected_left_rank | selected_right_rank | selected_pair_error_to_target | selected_left_x | selected_left_y | selected_right_x | selected_right_y | left_candidate_count | right_candidate_count | canvas_left_h_11 | canvas_left_h_12 | canvas_left_h_13 | canvas_left_h_21 | canvas_left_h_22 | canvas_left_h_23 | canvas_left_h_31 | canvas_left_h_32 | canvas_left_h_33 | canvas_right_h_11 | canvas_right_h_12 | canvas_right_h_13 | canvas_right_h_21 | canvas_right_h_22 | canvas_right_h_23 | canvas_right_h_31 | canvas_right_h_32 | canvas_right_h_33
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

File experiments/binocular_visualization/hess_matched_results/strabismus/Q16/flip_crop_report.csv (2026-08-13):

frame | source_width | source_height | crop_left | crop_top | crop_right | crop_bottom | crop_width | crop_height | invalid_pixels_inside_crop | output_width | output_height
frame_0000.jpg | 1750 | 1238 | 116 | 0 | 1712 | 1170 | 1596 | 1170 | 0 | 1596 | 1170
frame_0002.jpg | 1734 | 1236 | 105 | 0 | 1701 | 1179 | 1596 | 1179 | 0 | 1596 | 1179
frame_0004.jpg | 1737 | 1237 | 99 | 0 | 1695 | 1186 | 1596 | 1186 | 0 | 1596 | 1186
frame_0006.jpg | 1736 | 1236 | 99 | 0 | 1695 | 1186 | 1596 | 1186 | 0 | 1596 | 1186
frame_0008.jpg | 1736 | 1237 | 102 | 0 | 1698 | 1187 | 1596 | 1187 | 0 | 1596 | 1187
frame_0010.jpg | 1735 | 1236 | 104 | 0 | 1700 | 1188 | 1596 | 1188 | 0 | 1596 | 1188
frame_0012.jpg | 1739 | 1236 | 110 | 0 | 1706 | 1189 | 1596 | 1189 | 0 | 1596 | 1189
frame_0014.jpg | 1742 | 1237 | 56 | 75 | 1742 | 1179 | 1686 | 1104 | 0 | 1686 | 1104
frame_0016.jpg | 1761 | 1251 | 125 | 0 | 1721 | 1196 | 1596 | 1196 | 0 | 1596 | 1196
frame_0018.jpg | 1762 | 1249 | 125 | 0 | 1721 | 1197 | 1596 | 1197 | 0 | 1596 | 1197
frame_0020.jpg | 1765 | 1251 | 128 | 0 | 1724 | 1197 | 1596 | 1197 | 0 | 1596 | 1197
frame_0022.jpg | 1765 | 1251 | 75 | 85 | 1765 | 1180 | 1690 | 1095 | 0 | 1690 | 1095
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

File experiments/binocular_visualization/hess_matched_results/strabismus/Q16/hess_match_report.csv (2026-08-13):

frame | stem | frame_index | left_path | right_path | base_stitched_path | output_path | output_width | output_height | hess_residual_x | hess_residual_y | target_dx | target_dy | measured_dx | measured_dy | raw_correction_dx | raw_correction_dy | raw_correction_norm | correction_dx | correction_dy | correction_norm | correction_interpolated | left_translation_x | left_translation_y | right_translation_x | right_translation_y | selected_left_rank | selected_right_rank | selected_pair_error_to_target | selected_left_x | selected_left_y | selected_right_x | selected_right_y | left_candidate_count | right_candidate_count | canvas_left_h_11 | canvas_left_h_12 | canvas_left_h_13 | canvas_left_h_21 | canvas_left_h_22 | canvas_left_h_23 | canvas_left_h_31 | canvas_left_h_32 | canvas_left_h_33 | canvas_right_h_11 | canvas_right_h_12 | canvas_right_h_13 | canvas_right_h_21 | canvas_right_h_22 | canvas_right_h_23 | canvas_right_h_31 | canvas_right_h_32 | canvas_right_h_33
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

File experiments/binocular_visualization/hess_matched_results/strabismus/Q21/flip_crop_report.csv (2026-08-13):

frame | source_width | source_height | crop_left | crop_top | crop_right | crop_bottom | crop_width | crop_height | invalid_pixels_inside_crop | output_width | output_height
frame_0000.jpg | 1750 | 1238 | 122 | 0 | 1718 | 1180 | 1596 | 1180 | 0 | 1596 | 1180
frame_0002.jpg | 1734 | 1236 | 105 | 0 | 1701 | 1189 | 1596 | 1189 | 0 | 1596 | 1189
frame_0004.jpg | 1737 | 1237 | 104 | 0 | 1700 | 1198 | 1596 | 1198 | 0 | 1596 | 1198
frame_0006.jpg | 1736 | 1236 | 104 | 0 | 1700 | 1198 | 1596 | 1198 | 0 | 1596 | 1198
frame_0008.jpg | 1736 | 1237 | 105 | 3 | 1701 | 1199 | 1596 | 1196 | 0 | 1596 | 1196
frame_0010.jpg | 1735 | 1236 | 108 | 0 | 1704 | 1196 | 1596 | 1196 | 0 | 1596 | 1196
frame_0012.jpg | 1739 | 1236 | 113 | 0 | 1709 | 1195 | 1596 | 1195 | 0 | 1596 | 1195
frame_0014.jpg | 1742 | 1237 | 115 | 0 | 1711 | 1197 | 1596 | 1197 | 0 | 1596 | 1197
frame_0016.jpg | 1761 | 1251 | 128 | 7 | 1724 | 1203 | 1596 | 1196 | 0 | 1596 | 1196
frame_0018.jpg | 1762 | 1249 | 129 | 7 | 1725 | 1203 | 1596 | 1196 | 0 | 1596 | 1196
frame_0020.jpg | 1765 | 1251 | 132 | 7 | 1728 | 1203 | 1596 | 1196 | 0 | 1596 | 1196
frame_0022.jpg | 1765 | 1251 | 132 | 7 | 1728 | 1203 | 1596 | 1196 | 0 | 1596 | 1196
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

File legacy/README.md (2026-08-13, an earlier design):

# Legacy

This folder is reserved for historical material that has not yet been migrated
into the current project structure.

The active runtime code is in `src/cable_driven_eye_robot/` and the runnable
demo entry points are in `demos/`. Earlier joystick and eye-tracker replay
scripts were replaced by modular demos and are no longer kept here.

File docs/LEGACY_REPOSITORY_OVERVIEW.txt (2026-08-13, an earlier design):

Cable-driven Eye Robot Dataset and Codes
========================================

This file preserves the older repository overview for historical context. The
current GitHub layout has been reorganized into clearer engineering categories.

Current folder mapping
----------------------

1) src/cable_driven_eye_robot and demos
- Earlier control programs for the robotic eye platform have been replaced by
  modular runtime code.
- The active joystick, feedback, and eye-tracker replay demos now live in demos/.

2) experiments/open_loop_accuracy
- Data collected from pure open-loop inverse-kinematic control experiments.
- Used to evaluate positioning accuracy without feedback control.

3) experiments/eye_tracking
- Eye-gaze data collected from participants using an eye tracker.
- Used to reconstruct and analyze human eye trajectories.

4) experiments/binocular_visualization/homography
- Code and notebooks for homography-based binocular visualization.

5) hardware/cad
- Exported mechanical parts for the cable-driven robotic eye.

6) experiments/binocular_visualization/strabismus_severity
- Data and scripts used to simulate and quantify strabismus visual symptoms.

7) media/videos
- Videos demonstrating robotic-eye movements and binocular view synthesis.
- Includes healthy vision, strabismus simulation, and calibration videos.

GitHub Link for This Repository
-------------------------------

To clone this repository:

https://github.com/GMUYidi/Cable-driven-Eye-Robot.git

To view or share the webpage:

https://github.com/GMUYidi/Cable-driven-Eye-Robot

Note
----

- For questions and collaboration, please contact: yhuang35@gmu.edu
- When pushing updates, please follow the Git upload guide in the prepared README.txt to avoid errors.

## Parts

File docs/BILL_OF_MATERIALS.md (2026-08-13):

# Bill of Materials

This document lists the main hardware required to reproduce the current
cable-driven binocular robotic-eye platform.

## Core Actuation

| Item | Quantity | Current Part / Specification | Purpose |
| --- | ---: | --- | --- |
| Dynamixel servo | 12 | ROBOTIS Dynamixel XL330-M288-T | Cable actuation, 6 motors per eye |
| U2D2 | 1 | ROBOTIS U2D2 | USB-to-Dynamixel communication |
| U2D2 Power Hub Board | 1 | ROBOTIS U2D2 Power Hub Board | Injects external power into Dynamixel bus |
| DC power adapter | 1 | Reported current adapter: 12 V / 5 A | External supply for Power Hub; verify/regulate actual servo bus voltage before use |

## Sensors

| Item | Quantity | Current Part / Specification | Purpose |
| --- | ---: | --- | --- |
| IMU | 2 | Adafruit 9-DOF Absolute Orientation IMU Fusion Breakout - BNO055 | Measures left/right eye pose |
| Camera board | 2 | ESP32-S3-CAM Development Board with OV3660 Camera + Antenna, ESP32-S3 N16R8, 16 MB flash, 8 MB PSRAM | Eye-view camera stream |

## Mechanical Parts

The current 3D-printable parts are stored in:

```text
hardware/cad/fusion360_stl/
```

Existing STL exports include:

- Front half of the eyeball adapted for the BNO055 IMU.
- Rear half of the eyeball adapted for the BNO055 IMU.
- Main base of left eye.
- Main base of right eye.
- Front eye support of left eye.
- Front eye support of right eye.
- Servo spool 1.
- Servo spool 2.
- Bolt.

## Consumables and Mechanical Hardware

The exact fastener and cable list still needs to be finalized. The repository
should eventually document:

- Cable or string type and diameter.
- Screws, nuts, bearings, inserts, and shafts.
- Spool dimensions.
- Cable anchor method.
- 3D printing material and print settings.

## Power Notes

The reported servo power path is:

```text
external adapter -> U2D2 Power Hub Board -> Dynamixel servo bus
```

The computer USB connection powers the U2D2 electronics, but the servos should
be powered by the external adapter through the Power Hub Board.

Important: the reported adapter is 12 V / 5 A, but the XL330-M288-T servo bus
voltage must be verified or regulated before use. Do not treat the adapter
voltage as automatically safe for the servo unless the Power Hub/regulator
configuration has been measured.

## Information Still Needed

To make this BOM complete, add:

- Purchase links for each part.
- Confirmed servo bus voltage measured at the Dynamixel connector.
- Exact number and size of screws/fasteners.
- Cable material and length.
- 3D print settings.
- Any custom PCB, adapter, or mounting hardware.

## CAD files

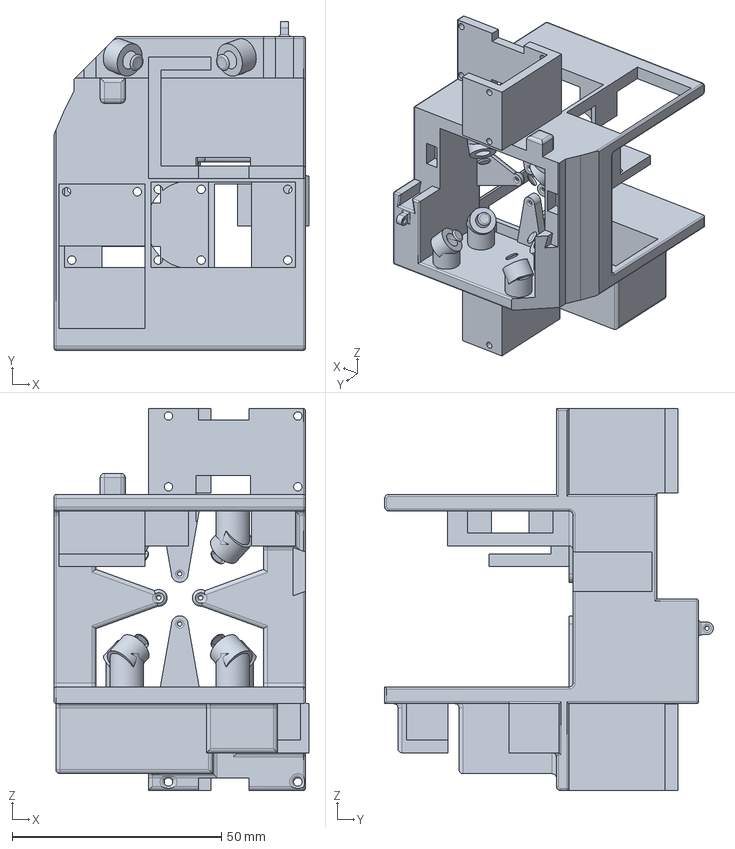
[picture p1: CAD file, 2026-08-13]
hardware/cad/step/main_base_left_eye.step
60.8 x 78.5 x 91.2 mm

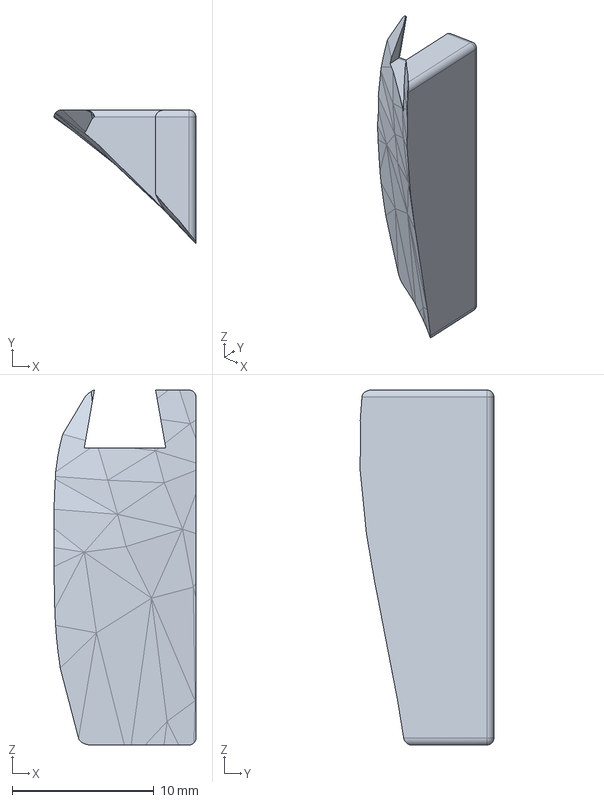
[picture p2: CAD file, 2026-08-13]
hardware/cad/step/main_base_right_eye.step
10.0 x 9.43 x 25.0 mm

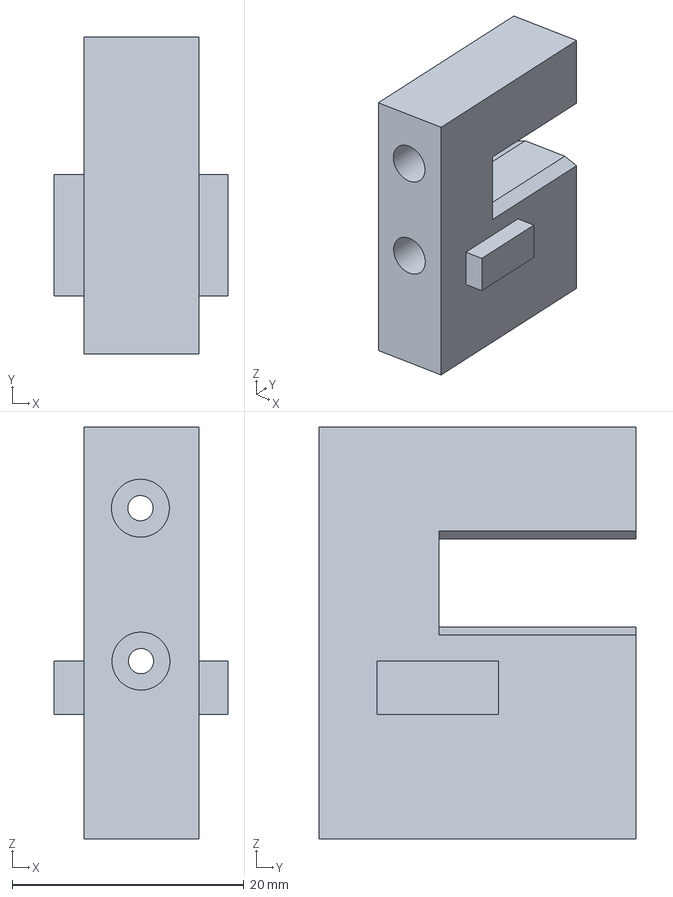
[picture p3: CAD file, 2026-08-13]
hardware/cad/step/connection.step
15.0 x 27.3 x 35.5 mm

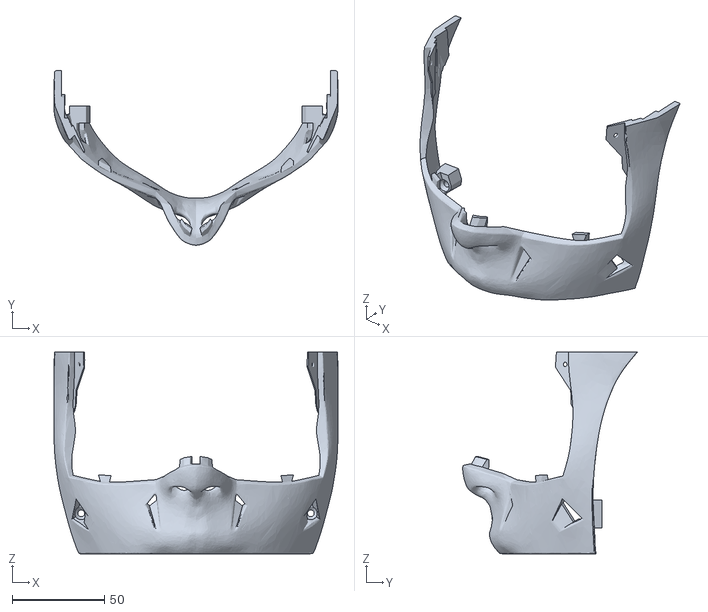
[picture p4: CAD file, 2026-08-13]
hardware/cad/stl/face_cover_lower.stl
154.1 x 94.7 x 109.4

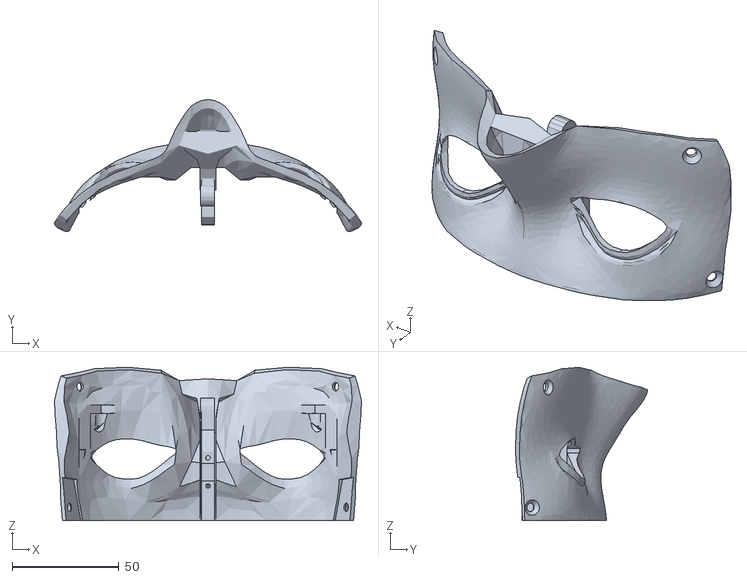
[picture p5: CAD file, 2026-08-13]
hardware/cad/stl/face_cover_upper.stl
143.6 x 61.7 x 71.7

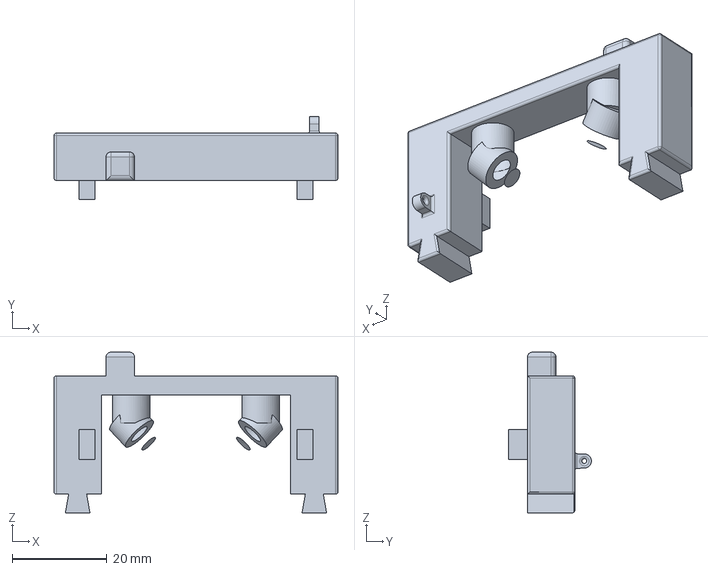
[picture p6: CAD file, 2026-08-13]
hardware/cad/step/front_eye_support_left.step
60.0 x 17.5 x 33.9 mm

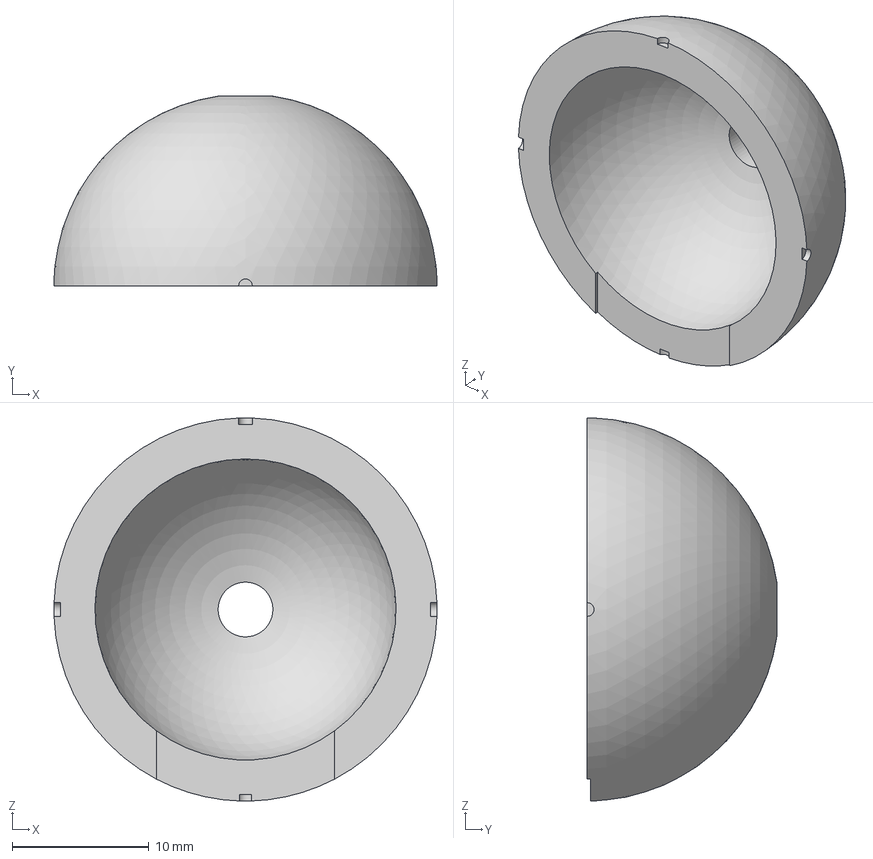
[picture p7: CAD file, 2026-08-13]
hardware/cad/step/eyeball_r2.step
28.0 x 13.9 x 28.0 mm

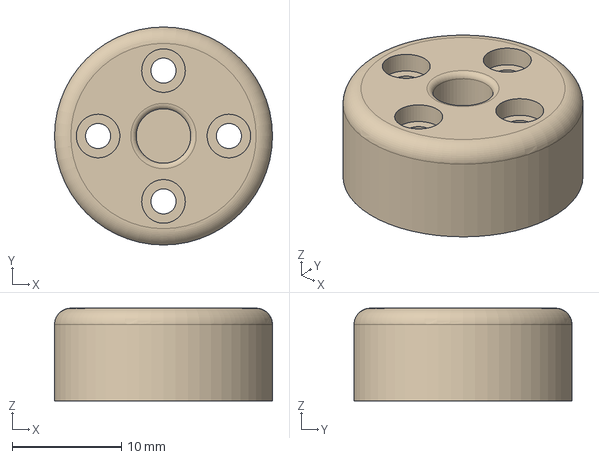
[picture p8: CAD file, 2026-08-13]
hardware/cad/step/servo_spool_1.step
20.0 x 20.0 x 8.50 mm

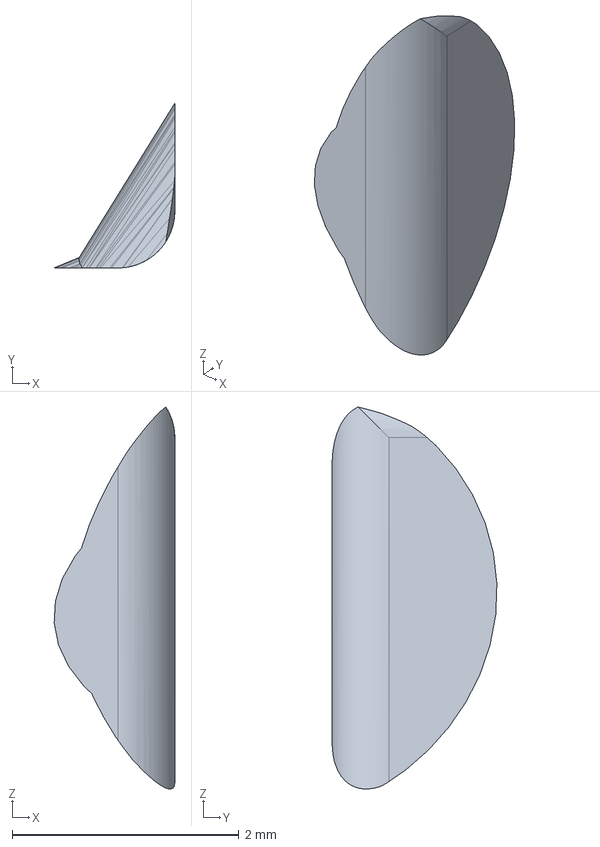
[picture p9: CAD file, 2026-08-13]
hardware/cad/step/front_eye_support_right.step
1.06 x 1.45 x 3.37 mm

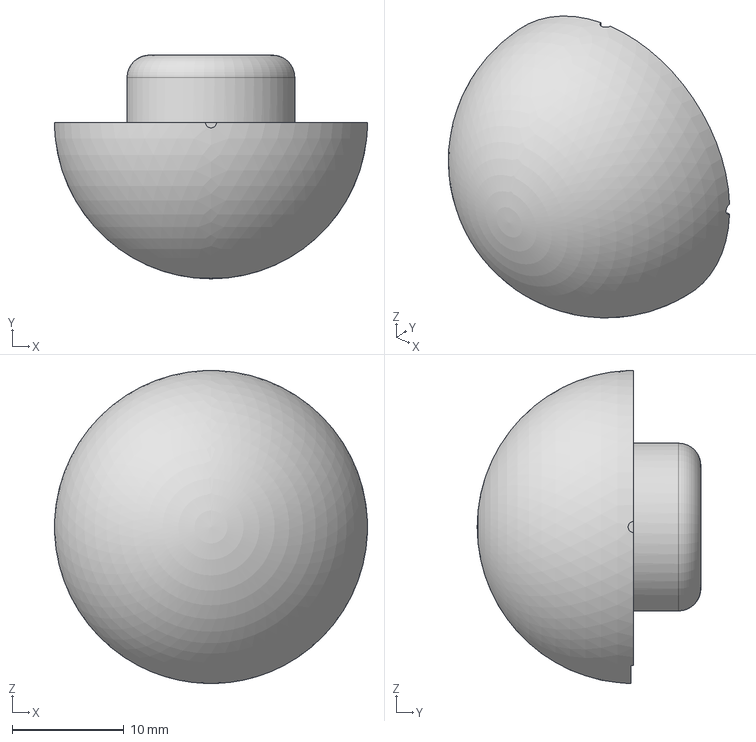
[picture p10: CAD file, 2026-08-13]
hardware/cad/step/eyeball_l1.step
28.0 x 20.0 x 28.0 mm

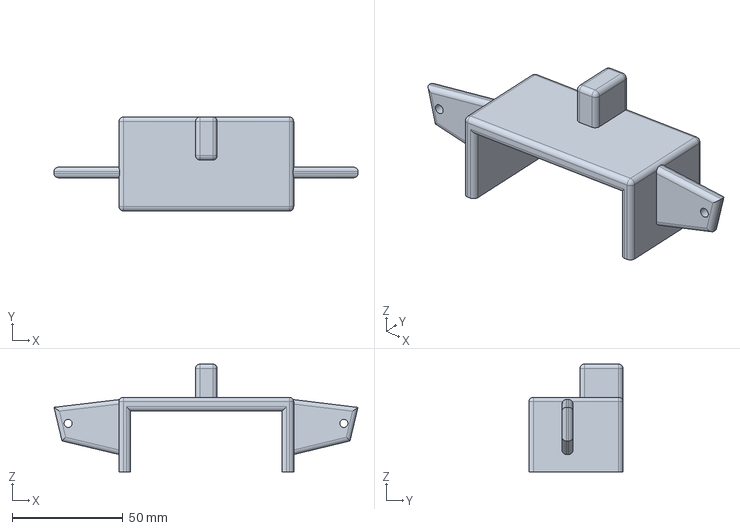
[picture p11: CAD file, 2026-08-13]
hardware/cad/step/support4.step
137.4 x 42.5 x 48.7 mm

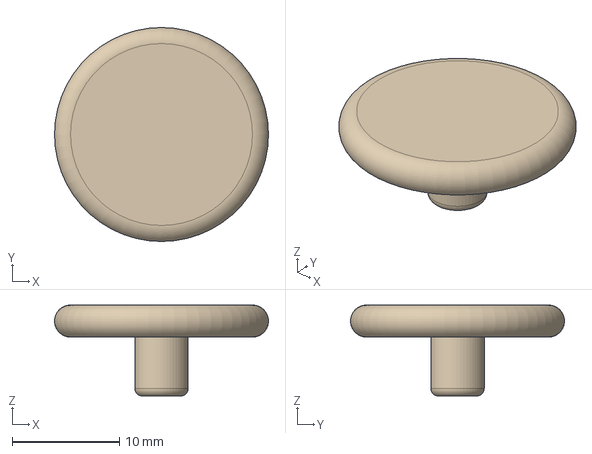
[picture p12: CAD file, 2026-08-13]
hardware/cad/step/servo_spool_2.step
20.0 x 20.0 x 8.50 mm

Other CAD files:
hardware/cad/step/eyeball_l2.step
hardware/cad/step/eyeball_r1.step
hardware/cad/fusion360_source/headlike_robotic_eye_assembly.f3z
hardware/cad/stl/connection.stl
hardware/cad/stl/eyeball_l1.stl
hardware/cad/stl/eyeball_l2.stl
hardware/cad/stl/eyeball_r1.stl
hardware/cad/stl/eyeball_r2.stl
hardware/cad/stl/front_eye_support_left.stl
hardware/cad/stl/front_eye_support_right.stl
hardware/cad/stl/main_base_left_eye.stl
hardware/cad/stl/main_base_right_eye.stl
hardware/cad/stl/servo_spool_1.stl
hardware/cad/stl/servo_spool_2.stl
hardware/cad/stl/support4.stl

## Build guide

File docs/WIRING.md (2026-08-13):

# Wiring and Power

This document describes the current wiring architecture for the cable-driven
robotic-eye platform.

## Dynamixel Power and Communication

The Dynamixel bus is connected through a ROBOTIS U2D2 and U2D2 Power Hub Board.

```text
Computer USB
   |
   | USB: communication + power for U2D2 electronics
   v
U2D2
   |
   | TTL / RS485 Dynamixel communication
   v
U2D2 Power Hub Board <---- external supply
                             reported: 12 V / 5 A adapter
                             required: verify/regulate for XL330 bus voltage
   |
   | communication + servo power
   v
Dynamixel XL330-M288-T servos
```

## Important Safety Checks

Before powering the robot:

- Confirm the actual voltage measured at the Dynamixel bus.
- Confirm that the bus voltage is safe for the XL330-M288-T servos.
- Confirm that the adapter polarity matches the Power Hub requirement.
- Confirm that the servo bus connectors are fully seated.
- Confirm that no cable is wrapped around a moving joint or spool.
- Start with the robot near its neutral mechanical pose.
- Keep access to the power switch or adapter plug during first motion tests.

## Dynamixel Bus

The current robot uses 12 Dynamixel XL330-M288-T servos on one coordinated bus.

| Motor ID | Eye | Muscle / Cable |
| --- | --- | --- |
| 1 | Left | LR |
| 2 | Left | MR |
| 3 | Left | SR |
| 4 | Left | IR |
| 5 | Left | SO |
| 6 | Left | IO |
| 7 | Right | MR |
| 8 | Right | LR |
| 9 | Right | SR |
| 10 | Right | IR |
| 11 | Right | SO |
| 12 | Right | IO |

Recommended physical practice:

- Label each motor with its ID.
- Label each cable with its muscle name.
- Photograph the final wiring and cable routing.
- Keep a saved Dynamixel Wizard screenshot showing all detected IDs.
- Save a measured bus-voltage note before running the motors.

## IMU Connections

The IMU model is:

```text
Adafruit 9-DOF Absolute Orientation IMU Fusion Breakout - BNO055
```

The current host-side demo expects two IMU streams:

```text
Left IMU:  COM11
Right IMU: COM6
Baudrate:  921600
```

These port names are machine-specific. If another computer is used, update the
port names in the demo script or pass command-line arguments when supported.

## Camera Connections

The camera model is:

```text
ESP32-S3-CAM Development Board with OV3660 Camera + Antenna
ESP32-S3 N16R8 module, 16 MB flash, 8 MB PSRAM
```

The current integrated dashboard uses Wi-Fi camera streams. Current default
stream URLs are:

```text
Left camera:  http://192.168.4.1/stream
Right camera: http://192.168.4.200/stream
```

These IP addresses depend on the ESP32 Wi-Fi mode and network configuration.

## Firmware

ESP32 camera/IMU firmware:

```text
firmware/esp32_imu_camera/IMUcamera.ino
```

Local Wi-Fi credentials should be stored in `wifi_secrets.h`. Do not commit that
file to git.

## Still Needed

To complete this page, add:

- A photo of the real U2D2 + Power Hub wiring.
- A measured voltage value at the Dynamixel bus.
- A photo of the full Dynamixel bus.
- A photo of left/right IMU placement.
- A photo of left/right ESP32-S3-CAM mounting.
- A drawn or exported wiring diagram.

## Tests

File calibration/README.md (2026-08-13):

# Calibration

This folder stores reusable calibration artifacts used by the robotic-eye
software. Calibration files are separated by type so camera, motor, IMU, and
pixel-to-gaze calibration do not become mixed together.

Current structure:

```text
calibration/
  camera_intrinsics/
    camera_parameter_left_or_default.npz
    camera_parameter_right.npz
```

Recommended future files:

```text
calibration/
  motor_neutral/
  eye_geometry/
  imu_zero_offsets/
  pixel_to_gaze/
```

Every calibration file should include:

- Date.
- Hardware version.
- Operator.
- Sensor or motor IDs.
- Method used to collect the calibration.
- Valid motion range.

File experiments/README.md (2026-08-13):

# Experiments

This folder stores datasets, analysis scripts, and outputs from robotic-eye and
binocular-vision experiments.

```text
experiments/
  open_loop_accuracy/          pure inverse-kinematic control accuracy tests
  eye_tracking/                participant eye-tracking trajectories
  binocular_visualization/     homography and strabismus visualization outputs
```

Reusable calibration files belong in `calibration/`. Videos belong in
`media/videos/`. Runtime software belongs in `src/` and `demos/`.

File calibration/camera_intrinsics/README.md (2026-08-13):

# Camera Intrinsics

Camera intrinsic calibration files for the ESP32-S3-CAM OV3660 modules.

Current files:

- `camera_parameter_left_or_default.npz`
- `camera_parameter_right.npz`

Each calibration artifact should record the camera identity, image resolution,
calibration target, collection date, and the script or notebook used to produce
it.

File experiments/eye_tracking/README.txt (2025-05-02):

# Human Eye Gaze Trajectory Dataset (Processed)

This repository contains processed human eye gaze trajectory data collected using an eye tracker during standardized video watching tasks. The data has been processed to remove noise and interference artifacts, and is used to drive a robotic eye platform to replicate human eye movements.

This dataset is associated with the Scientific Reports manuscript:

**"A Novel Cable-driven Eye Robot For Human Vision Visualization and Strabismus Diagnosis"**

## Dataset Overview

- **Format**: MATLAB `.mat` file
- **Content**:
  - Smoothed and cleaned eye gaze angles (Yaw and Pitch for left and right eyes)
  - Total number of frames: 500 frames and 150 frames(two types) 
  - Sampling frequency: 30 Hz

## Data Description

The file contains the following variables:

- **GazeAngleSmoothed_cell**: A matrix where each row corresponds to a sampled timestamp and columns represent the following:
    - Column 1: Right Eye Yaw (degrees)
    - Column 2: Right Eye Pitch (degrees)
    - Column 3: Left Eye Yaw (degrees)
    - Column 4: Left Eye Pitch (degrees)

All angles are in degrees and have been smoothed and processed to remove interference.

## Data Collection Method

- **Device**: Viewpoint Eye Tracker®
- **Task**: Participants were instructed to watch a standardized video and track a moving green dot target on the screen.
- **Environment**: Monitors were positioned at a fixed distance with the eye tracker mounted below.
- **Processing**: Raw gaze data was smoothed and filtered to remove sudden jumps, blinks, and other noise artifacts.

## Usage

The data can be used for:

- Driving robotic eye platforms to mimic human eye movements
- Validating gaze control algorithms
- Studying human eye movement characteristics during visual tasks

## License

This dataset is released under the MIT License for academic research purposes. Please contact the authors for commercial use or if used in a publication.

## Citation

If you use this dataset, please cite:

> Yidi Huang, Qi Wei, Joseph L. Demer, and Ningshi Yao. A Novel Cable-driven Eye Robot For Human Vision Visualization and Strabismus Diagnosis. Scientific Reports, 2025.

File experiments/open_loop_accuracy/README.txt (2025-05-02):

Accuracy Test of Pure Open-loop Control Under Inverse Kinematics

This folder contains experimental data and analysis code used to evaluate the accuracy of a pure open-loop control strategy based on inverse kinematics for robotic eye movement.

Overview

The test aims to verify how precisely the robotic eye can follow desired gaze angles (yaw and pitch) when driven purely by inverse kinematics calculations, without real-time feedback correction.

Files included

📄 data_test_open_loop.txt
- Recorded dataset of robotic eye movement tests
- Contains measured vs. target yaw, pitch, and roll angles during open-loop operation
- Columns:
  - Column 1: Actual yaw angle (degrees)
  - Column 2: Actual pitch angle (degrees)
  - Column 3: Actual roll angle (degrees)
  - Column 4: Target yaw angle (degrees)
  - Column 5: Target pitch angle (degrees)
  - Column 6: Target roll angle (degrees)

📄 bilinear_interpolation_eachangle.m
- MATLAB script to process the above dataset
- Generates 2D contour heatmaps visualizing:
  - Yaw angle errors
  - Pitch angle errors
  - Roll angle errors
- The heatmaps provide intuitive representations of open-loop control performance across different gaze angles.

How to use

1. Open bilinear_interpolation_eachangle.m in MATLAB.
2. Ensure data_test_open_loop.txt is in the same directory or adjust the path.
3. Run the script.
4. The following plots will be generated and displayed:
    - Yaw error heatmap
    - Pitch error heatmap
    - Roll error heatmap

Purpose

These files were used in the study to:
- Evaluate the accuracy and limitations of pure inverse kinematics-based open-loop control.
- Provide quantitative and visualized results for robotic eye design and control algorithm validation.

License

The dataset and code are released for academic research use under the MIT License.

Citation

If you use these files for your research or publications, please cite:

Yidi Huang, Qi Wei, Joseph L. Demer, and Ningshi Yao. A Novel Cable-driven Eye Robot For Human Vision Visualization and Strabismus Diagnosis. Scientific Reports, 2025.

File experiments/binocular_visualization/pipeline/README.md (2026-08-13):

# Binocular Visualization Pipeline

This folder archives the scripts used to generate the Hess-matched binocular
visualization videos in `../hess_matched_results/`.

These scripts are experiment-pipeline code, not the real-time robot-control
runtime. They are kept here so the generated videos are traceable and so future
work can gradually refactor the pipeline into cleaner reusable modules.

## Pipeline Stages

```text
robotic-eye capture / replay
  -> healthy binocular baseline frames
  -> Hess-chart extraction and interpolation
  -> simulated strabismus gaze trajectory
  -> homography matching / frame warping
  -> cropped and stabilized binocular video
  -> optional gaze overlay
```

## Folder Layout

```text
pipeline/
  acquisition/                  robot capture/replay scripts for the healthy baseline
  hess_chart/
    app_functions/              MATLAB helper functions for Hess-chart point extraction
    bilinear_interpolation/     Hess interpolation and strabismus trajectory simulation
  makevideo/                    video stitching, homography, repair, crop, and overlay scripts
```

## Relationship To Results

The final uploaded results live in:

```text
experiments/binocular_visualization/hess_matched_results/
```

For each strabismus subject, the result folder includes the final video,
homography/report metadata, and matrix files. Intermediate frame folders are not
committed because they are large and can be regenerated by the pipeline.

## Current Status

This folder is an archived research pipeline. The scripts preserve the actual
workflow used to create the current videos, including subject-specific repair or
refinement scripts. The next engineering step is to convert the repeated logic
into a single parameterized command-line pipeline.

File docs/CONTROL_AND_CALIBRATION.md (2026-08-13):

# Control and Calibration Architecture

## Control Objective

The control objective is to convert a desired gaze target into coordinated
two-eye motion, then measure how accurately the physical eyes follow that target.

The current control path is:

```text
joystick or scripted target
  -> desired yaw and pitch
  -> optional torsional roll from Listing-style geometry
  -> left/right eye kinematics
  -> six actuator pulse changes per eye
  -> Dynamixel goal positions
  -> physical cable-driven motion
  -> IMU and camera feedback
```

## Open-Loop Control

The main current demo is open-loop:

- The joystick defines target yaw and pitch.
- The model computes cable/muscle length changes.
- Motor goal positions are sent directly.
- There is no real-time correction from measured IMU error in the basic demo.

Open-loop control is useful because it tests the mechanical model, motor mapping,
and cable routing without hiding errors behind feedback.

## Feedback Control

Feedback-control experiment scripts use IMU pose as the actual eye orientation.
The controller compares target pose and actual pose, then updates the command.

The feedback-control demo uses this structure:

```text
joystick target
  -> target eye pose
  -> open-loop inverse kinematics
  -> feedforward motor pulses
  -> IMU pose error
  -> bounded PD-style correction on antagonistic motor pairs
  -> corrected motor command
```

This is intentionally conservative. The open-loop model remains the main motor
command, and feedback adds a bounded correction rather than replacing the model.

Feedback control should eventually be organized into explicit modes:

- Open-loop inverse kinematics.
- IMU feedback correction.
- Feedforward plus feedback.
- Calibration-grid collection.
- Offline replay.

The current scripted closed-loop experiment is:

```text
Hess-chart target
  -> left/right target eye pose
  -> open-loop inverse kinematics
  -> IMU feedback correction
  -> consecutive in-tolerance samples
  -> synchronized camera capture
  -> summary and sample telemetry
```

It is implemented in:

```text
demos/hess_chart_tracking.py
src/cable_driven_eye_robot/apps/hess_chart_tracking.py
src/cable_driven_eye_robot/data/hess_chart.py
```

## Kinematic Model

The modular control code represents each eye with:

- Eyeball radius.
- Muscle insertion points.
- Pulley points.
- Per-muscle pulse scales.
- Per-muscle offsets.

For each desired eye pose, the model rotates the muscle insertion points and
computes the change in cable path length relative to the pulley geometry.

The current model is implemented in:

```text
src/cable_driven_eye_robot/kinematics.py
```

## Torsion / Listing-Style Roll

The project includes a helper that estimates roll from horizontal and vertical
gaze angle. This gives a more eye-like torsional behavior than commanding yaw
and pitch alone.

The current helper is implemented in:

```text
src/cable_driven_eye_robot/math_utils.py
```

## Calibration Layers

The system needs several independent calibrations.

### Motor Neutral Calibration

Defines the "straight ahead" or neutral pose of every motor.

Outputs:

- Perfect motor positions.
- Baseline present positions.
- Per-eye neutral pose.

### Kinematic Calibration

Fits the relationship between target eye pose and actuator motion.

Outputs:

- Pulse scale per muscle.
- Pulse offset per muscle.
- Valid motion range.
- Expected error over a yaw/pitch grid.

### IMU Calibration

Maps raw IMU yaw, pitch, and roll into robot-eye pose.

Outputs:

- Zero pose.
- Axis sign convention.
- Roll offset.
- Valid sample age threshold.

### Camera Intrinsic Calibration

Corrects lens distortion and defines camera matrix.

Current calibration files are stored in:

```text
calibration/camera_intrinsics/
```

Outputs:

- Camera matrix.
- Distortion coefficients.
- Resolution.
- Camera identity.

### Pixel-to-Gaze Calibration

Maps eye pose to pixel location in the eye camera frame.

This is required for foveated visualization because the system must know where
the high-resolution foveal center should be placed in the image.

Recommended method:

1. Place a known visual target in front of the eyes.
2. Command a grid of yaw/pitch targets.
3. Capture camera frames and IMU pose at each grid point.
4. Detect the target in image coordinates.
5. Fit a mapping from `(yaw_deg, pitch_deg)` to `(u_px, v_px)`.
6. Validate the mapping on held-out points.

## Telemetry

Each experiment should log:

- Timestamp.
- Target yaw, pitch, and roll.
- Commanded left/right pose.
- Measured left/right IMU pose.
- Pose error.
- Motor goal positions.
- Motor present positions.
- Motor present current if available.
- Camera frame index or video timestamp.
- Experiment stage.
- Safety events.

This makes the project more credible because a demo can be backed by measured
tracking performance.

## Success Criteria

A mature demo should be able to show:

- Repeatable saccade or gaze-step commands.
- Target vs actual pose plots.
- Final fixation error.
- Overshoot and settling time.
- Camera view synchronized with eye pose.
- Gaze-center overlay in the image.
- Foveated rendering around the gaze center.

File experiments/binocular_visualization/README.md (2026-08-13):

# Binocular Visualization Experiments

This folder groups outputs related to reconstructing and visualizing binocular
vision from two robotic-eye viewpoints.

```text
binocular_visualization/
  homography/               homography estimation and visualization scripts
  strabismus_severity/      strabismus severity data and plotting scripts
  pipeline/                 archived generation scripts for visualization videos
  hess_matched_results/     final Hess-matched binocular videos and metadata
```

These are experiment outputs and analysis tools, not core runtime control code.

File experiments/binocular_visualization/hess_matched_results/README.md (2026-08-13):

# Hess-Matched Binocular Visualization Results

This folder contains representative binocular visualization results for
Hess-chart-matched strabismus simulations and a healthy binocular reference.

The goal of this experiment is to visualize how the scene seen by the robotic
eyes changes when the binocular view is warped according to Hess-chart-derived
strabismus motion, then compare it against the corresponding healthy binocular
view.

## Included Results

```text
hess_matched_results/
  RESULTS_MANIFEST.csv
  FILE_MANIFEST.csv
  healthy_reference/
    stitched_frames_flipped_cropped_60fps.mp4
    flip_crop_metadata.json
    flip_crop_report.csv
    ffmpeg_frames_health_second.txt
    matrices/
  strabismus/
    Q3/
    Q11/
    Q13/
    ...
    Q48/
```

Each strabismus subject folder includes:

- `stitched_frames_flipped_cropped_60fps_with_gaze_<subject>_lead0p5s.mp4`
- `hess_match_metadata.json`
- `hess_match_report.csv`
- `flip_crop_metadata.json`
- `flip_crop_report.csv`
- `matrices/*.npz`

The healthy reference folder includes:

- `stitched_frames_flipped_cropped_60fps.mp4`
- `flip_crop_metadata.json`
- `flip_crop_report.csv`
- `ffmpeg_frames_health_second.txt`
- `matrices/*.npz`

## Subject Set

The strabismus simulation set currently includes:

```text
Q3, Q11, Q13, Q14, Q16, Q21, Q22, Q23, Q27, Q29,
Q33, Q37, Q40, Q44, Q45, Q47, Q48
```

The `Q*` identifiers are anonymized Hess-chart subject IDs used to keep the
results traceable without exposing participant names.

## Manifests

`RESULTS_MANIFEST.csv` summarizes each result folder, source folder, final
video filename, video size, and data-file count.

`FILE_MANIFEST.csv` lists every copied result/data file with its relative path,
size, role, and SHA-256 checksum. This makes the copied results auditable after
uploading to GitHub.

## Generation Pipeline

The scripts used to generate these results are archived in:

```text
experiments/binocular_visualization/pipeline/
```

That pipeline contains the healthy-baseline capture/replay scripts, Hess-chart
interpolation tools, and video stitching/homography scripts used to produce the
current result videos.

## Excluded Intermediate Files

The original local result folders also contain thousands of intermediate JPEG
frames, debug frames, and temporary visual checks. Those files are intentionally
excluded from this repository because they are large and can be regenerated from
the video-generation pipeline.

The committed result package keeps the final videos and the small data files
needed to interpret or verify each result.

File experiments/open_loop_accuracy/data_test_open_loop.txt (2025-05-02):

-11.7963190784017 -10.1587995666296 2.61580633190026 -12 -9 0.947866317255314
-11.7735520157311 -8.49087791061898 2.72075276218987 -12 -8 0.842187427505944
-11.9682532959266 -7.44240045535246 2.33748697315433 -12 -7 0.73663600845071
-11.7716560359652 -5.99927275098358 2.96902155562662 -12 -6 0.631195959051181
-11.8419101884436 -4.49458658594736 2.27380587202886 -12 -5 0.525851245369782
-11.9756148987501 -3.41549152401511 1.99568511006008 -12 -4 0.420585890826413
-11.9303754452832 -2.83566406828854 1.75754790761563 -12 -3 0.315383966528068
-11.8632796201988 -1.29326916715731 1.24328752913799 -12 -2 0.210229581659043
-11.7606232911414 -0.610957975772084 1.89615292078015 -12 -1 0.105106873919471
-11.7587778662002 0.485837376067608 1.5202787634862 -12 0 -0
-11.9605967295806 1.1019192997991 1.12988545804669 -12 1 -0.105106873919471
-11.7573518045598 2.03690325076842 1.02812319085973 -12 2 -0.210229581659043
-11.7607082629393 3.17183906741037 1.37547687757306 -12 3 -0.315383966528068
-11.8786560878193 4.37302184707021 0.665549627342486 -12 4 -0.420585890826413
-11.7999298827778 4.31214748016962 0.407739416329562 -12 5 -0.525851245369782
-11.9645284153432 6.99681300348842 -0.56880278890587 -12 6 -0.631195959051181
-11.8945596793434 7.57253872900871 -0.884430020842217 -12 7 -0.73663600845071
-11.7710661187027 8.51733852773345 -0.157681371787149 -12 8 -0.842187427505944
-11.8019481676101 9.39199342949396 -2.18865549423226 -12 9 -0.947866317255314
-10.7601268934018 -9.63323739220553 4.1129491551131 -11 -9 0.868371096543306
-10.8360648252109 -8.93519373994679 4.23003212812397 -11 -8 0.771554640381072
-10.9910720803565 -7.44720630182408 4.08728471806218 -11 -7 0.674855175514952
-10.7877176735328 -6.19479248300912 4.14466910661704 -11 -6 0.578257924159972
-10.7665016880606 -5.06932008610166 4.033849303602 -11 -5 0.481748170283732
-10.8303162112856 -3.60943851947812 3.57225643477095 -11 -4 0.385311250639083
-10.8105649673554 -2.9483563014706 3.46297001693482 -11 -3 0.28893254586424
-10.8142168829688 -2.35099523913929 3.09453186408224 -11 -2 0.19259747163886
-10.9019432451165 -1.10334148408376 2.72400083891873 -11 -1 0.0962914698847564
-10.8361305274556 0.178605785933202 2.26696895982572 -11 0 -0
-10.9572033280471 0.481638048848525 2.15210414867649 -11 1 -0.0962914698847564
-10.8234884779951 1.41655427788349 1.71387379791913 -11 2 -0.19259747163886
-11.0079582115944 2.70317467474105 1.14628485607314 -11 3 -0.28893254586424
-10.9307692537598 4.31678642944982 0.561364338138063 -11 4 -0.385311250639083
-11.0115428476578 4.61676586321658 0.286644488098972 -11 5 -0.481748170283732
-11.024282945309 6.4966289248143 -0.289653851666515 -11 6 -0.578257924159972
-11.2058644570818 7.34897759433582 -1.05319283312187 -11 7 -0.674855175514952
-11.173707155744 6.50294415410353 -1.42475486477285 -11 8 -0.771554640381072
-11.0792748700152 7.99647865731606 -1.28809271978733 -11 9 -0.868371096543306
-9.76244448779041 -10.1081771412587 3.68495323642841 -10 -9 0.789008529832285
-9.99138847987427 -9.18374670626457 4.01838263628005 -10 -8 0.701039874460307
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

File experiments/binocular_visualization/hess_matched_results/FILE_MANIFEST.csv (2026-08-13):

cohort | subject | role | relative_path | size_mb | sha256
healthy_reference | health_second | final_video | experiments/binocular_visualization/hess_matched_results/healthy_reference/stitched_frames_flipped_cropped_60fps.mp4 | 21.343 | 17c430b3e9efac81e8f323bdc08775e42800371f0c0ee0e7008d3c312212abb5
healthy_reference | health_second | matrix_data | experiments/binocular_visualization/hess_matched_results/healthy_reference/matrices/flagged_frames.csv | 0.022 | 6509514e70543cbdbe5042fabeab807c4c8f069eed758ff9dfe1d41acc9261b3
healthy_reference | health_second | matrix_data | experiments/binocular_visualization/hess_matched_results/healthy_reference/matrices/homography_matrices_and_points.npz | 2.113 | 23f57686c6cbc4c7bea22ca126a434cd7e9243b0f50f80f1acb3ee2d59f95b9e
healthy_reference | health_second | matrix_data | experiments/binocular_visualization/hess_matched_results/healthy_reference/matrices/homography_matrices_and_points_before_initial_green_fix.npz | 1.767 | fa0fa1f017115c9450003d2859fa29363894bfdbd668ff287dd16a07285b33e1
healthy_reference | health_second | matrix_data | experiments/binocular_visualization/hess_matched_results/healthy_reference/matrices/homography_matrices_and_points_before_mid_green_fix.npz | 1.926 | 02175321f5e83f1ac972abb6b3e0ecb9f78ddbfbd9506fedf3bbe44536e9d191
healthy_reference | health_second | matrix_data | experiments/binocular_visualization/hess_matched_results/healthy_reference/matrices/homography_summary.csv | 0.763 | 889da145a5d5aff7733d760ab33ba52a8ac3afb77b91534ec22d83ac5883a221
healthy_reference | health_second | matrix_data | experiments/binocular_visualization/hess_matched_results/healthy_reference/matrices/homography_summary_before_initial_green_fix.csv | 0.751 | bf7cd8fca62ae00ebf997f7890b179e6b3f034e775efaeeb7a74bcdd9ced79df
healthy_reference | health_second | matrix_data | experiments/binocular_visualization/hess_matched_results/healthy_reference/matrices/homography_summary_before_mid_green_fix.csv | 0.757 | 081211d30b4a2fade9dbe26b65c24bf6c8fa485c675ad7ea89524dcad9464e3a
healthy_reference | health_second | matrix_data | experiments/binocular_visualization/hess_matched_results/healthy_reference/matrices/initial_green_alignment_repair_metadata.json | 0 | 8ccd9ed65566bf9a811f500b7179ab52a6163aa6d6c55a5cf1e86e76b0c40484
healthy_reference | health_second | matrix_data | experiments/binocular_visualization/hess_matched_results/healthy_reference/matrices/initial_green_alignment_repair_report.csv | 0.021 | 74c5f3963f49d122123939119d1c58cac00f158cd56c21b8398fedb24c321842
healthy_reference | health_second | matrix_data | experiments/binocular_visualization/hess_matched_results/healthy_reference/matrices/mid_green_alignment_repair_metadata.json | 0.001 | bce459cf2363d7a12e64e7f330a61300d26d44773770cb0c949979789d2a8f27
healthy_reference | health_second | matrix_data | experiments/binocular_visualization/hess_matched_results/healthy_reference/matrices/mid_green_alignment_repair_report.csv | 0.031 | 4f55437a5355833e83429344949dab18f41bbac07eed2e86adbdf28d7107c930
healthy_reference | health_second | matrix_data | experiments/binocular_visualization/hess_matched_results/healthy_reference/matrices/run_metadata.json | 0.001 | 4de674be3ab4a8f66cde5c957e8e49599a4873b847ff20607270dc2da5fb0d3a
healthy_reference | health_second | metadata_or_report | experiments/binocular_visualization/hess_matched_results/healthy_reference/ffmpeg_frames_health_second.txt | 0.087 | ab9d646433c5045d475a931b98814ebf902eedbec49839169da4d98e6f60a0c4
healthy_reference | health_second | metadata_or_report | experiments/binocular_visualization/hess_matched_results/healthy_reference/flip_crop_metadata.json | 0 | 6740997bcb7c03b04eddd6aa4d914eadd0fcc361fe7887a5d982736f8139f9f4
healthy_reference | health_second | metadata_or_report | experiments/binocular_visualization/hess_matched_results/healthy_reference/flip_crop_report.csv | 0.056 | 1845132a9782ce5fb85ebab3ae6198c9a844004b4e0b80fe3c22552677334d92
strabismus | Q11 | final_video_with_gaze_overlay | experiments/binocular_visualization/hess_matched_results/strabismus/Q11/stitched_frames_flipped_cropped_60fps_with_gaze_Q11_lead0p5s.mp4 | 17.222 | 2f54f7812e4cba3a123ec3c7d9edb750eb6d7b77b5a3ce20db537b769830f5fb
strabismus | Q11 | matrix_data | experiments/binocular_visualization/hess_matched_results/strabismus/Q11/matrices/hess_matched_homographies_Q11.npz | 1.841 | 36b667b24665e2376e6ab3148e3e1111b8e50199f6e9248c49849eb9badb93a9
strabismus | Q11 | metadata_or_report | experiments/binocular_visualization/hess_matched_results/strabismus/Q11/flip_crop_metadata.json | 0 | a8060ef60395bc839708c97fe4f452e63b100b50762a3691561f6be9a1028f82
strabismus | Q11 | metadata_or_report | experiments/binocular_visualization/hess_matched_results/strabismus/Q11/flip_crop_report.csv | 0.056 | 3124c33d09376cf6b9e55356f9890ffd8198f84afeb68cea5ff4d1dd24a4c010
strabismus | Q11 | metadata_or_report | experiments/binocular_visualization/hess_matched_results/strabismus/Q11/hess_match_metadata.json | 0.002 | 1bbad8a6eea4e92a2a15cc4f58bd735723e0c487098828f726051a5dc63bbc82
strabismus | Q11 | metadata_or_report | experiments/binocular_visualization/hess_matched_results/strabismus/Q11/hess_match_report.csv | 0.784 | 8cf381344cf005a8cd206e330cd28b3d82f3b19aeedecef2ce90d816dd2ad3ab
strabismus | Q13 | final_video_with_gaze_overlay | experiments/binocular_visualization/hess_matched_results/strabismus/Q13/stitched_frames_flipped_cropped_60fps_with_gaze_Q13_lead0p5s.mp4 | 18.021 | b2e7ce62b280e68578e7ab3d99a453811ed3c83996dc0b3c50224fb8d2bfe39a
strabismus | Q13 | matrix_data | experiments/binocular_visualization/hess_matched_results/strabismus/Q13/matrices/hess_matched_homographies_Q13.npz | 1.841 | a3ece9421ff989f1c7096910522be8e0f170f8ed0b404ad497158fd87fbdafdf
strabismus | Q13 | metadata_or_report | experiments/binocular_visualization/hess_matched_results/strabismus/Q13/flip_crop_metadata.json | 0 | 3ce96e173aab82fe78becda50dc07fca9fa8e4bd78ba67d15a1a85b3df59447e
strabismus | Q13 | metadata_or_report | experiments/binocular_visualization/hess_matched_results/strabismus/Q13/flip_crop_report.csv | 0.056 | 534447ec669e74582382231e38f0363da9f31c4fbe92a247cef750ce0bf9b10d
strabismus | Q13 | metadata_or_report | experiments/binocular_visualization/hess_matched_results/strabismus/Q13/hess_match_metadata.json | 0.002 | 5ea050cbc559206913bb09b1fe39d20e936775351cd4901c9dea71c0e88e7ba1
strabismus | Q13 | metadata_or_report | experiments/binocular_visualization/hess_matched_results/strabismus/Q13/hess_match_report.csv | 0.783 | e04582a47ac7193b5d7d2858bc005e93d54ef269fc85f07cbf1751232770675a
strabismus | Q14 | final_video_with_gaze_overlay | experiments/binocular_visualization/hess_matched_results/strabismus/Q14/stitched_frames_flipped_cropped_60fps_with_gaze_Q14_lead0p5s.mp4 | 17.95 | 3699c1c10a35634753b228be1a7ace6f29b248b0cf49ca500d4b69121487cf0e
strabismus | Q14 | matrix_data | experiments/binocular_visualization/hess_matched_results/strabismus/Q14/matrices/hess_matched_homographies_Q14.npz | 2.255 | 4e9ac45b23238eb5e553f6c4e15a38d270714b9c39ba7323d91cc2951d14d6ec
strabismus | Q14 | metadata_or_report | experiments/binocular_visualization/hess_matched_results/strabismus/Q14/flip_crop_metadata.json | 0 | 371c0d3af618f74d7a4693bdf9a6eb1bc8345099b206401f482d817bbe77bfe7
strabismus | Q14 | metadata_or_report | experiments/binocular_visualization/hess_matched_results/strabismus/Q14/flip_crop_report.csv | 0.055 | 5508e0580fd470da0b0bbc8d1679974e1e1cc0f79a1c6b5864c96e88b96e7d2d
strabismus | Q14 | metadata_or_report | experiments/binocular_visualization/hess_matched_results/strabismus/Q14/hess_match_metadata.json | 0.002 | f0e1831abfb94770ed87b3add7caebe5f37aca512f5c306f4956da76ac9e1e49
strabismus | Q14 | metadata_or_report | experiments/binocular_visualization/hess_matched_results/strabismus/Q14/hess_match_report.csv | 0.833 | bc0053e5670ab88413c3b2b4863321b1c2621c01ce2df4749f28e2f4534314b1
strabismus | Q16 | final_video_with_gaze_overlay | experiments/binocular_visualization/hess_matched_results/strabismus/Q16/stitched_frames_flipped_cropped_60fps_with_gaze_Q16_lead0p5s.mp4 | 18.994 | f7e663823174cdd72f89035bad00f54258fab04a1ab0022b03658aa4159d748c
strabismus | Q16 | matrix_data | experiments/binocular_visualization/hess_matched_results/strabismus/Q16/matrices/hess_matched_homographies_Q16.npz | 2.255 | aced14be39fa5c52a0986616f06e425489fc3056908c1b0bdfd22ec42ad7be79
strabismus | Q16 | metadata_or_report | experiments/binocular_visualization/hess_matched_results/strabismus/Q16/flip_crop_metadata.json | 0 | 95baccf20778ff7c192587f0f66035cccfa15eb24fb7377815899feac5e7bd2a
strabismus | Q16 | metadata_or_report | experiments/binocular_visualization/hess_matched_results/strabismus/Q16/flip_crop_report.csv | 0.055 | 4737647f8eb589d51e4bd248f26bd3c39d1d323e4e935ce6ca4b3e2a2595a8b1
strabismus | Q16 | metadata_or_report | experiments/binocular_visualization/hess_matched_results/strabismus/Q16/hess_match_metadata.json | 0.002 | a43fcbcc71a4b0280883927a209a136c3e7fb5406e58f2a282c566fe74ce1391
strabismus | Q16 | metadata_or_report | experiments/binocular_visualization/hess_matched_results/strabismus/Q16/hess_match_report.csv | 0.833 | 50b3c4b8925aa629ff55657ead7b48cce6a3541d243a2caa036de7b813191197
strabismus | Q21 | final_video_with_gaze_overlay | experiments/binocular_visualization/hess_matched_results/strabismus/Q21/stitched_frames_flipped_cropped_60fps_with_gaze_Q21_lead0p5s.mp4 | 17.189 | cc2e4b2d07bef654971048b2f1c8cf54e0edf7ff7d77cfae03d962c6723c032f
strabismus | Q21 | matrix_data | experiments/binocular_visualization/hess_matched_results/strabismus/Q21/matrices/hess_matched_homographies_Q21.npz | 2.255 | 59249f3d7a3d294ffc95903f7dd18b6826c35641e6aa89f1eb0c5cddd88ad72f
strabismus | Q21 | metadata_or_report | experiments/binocular_visualization/hess_matched_results/strabismus/Q21/flip_crop_metadata.json | 0 | ebe38719ad8bebcbd2c44fdff154dbd26791f9bd0f2627c6f1cfce943b9670d2
strabismus | Q21 | metadata_or_report | experiments/binocular_visualization/hess_matched_results/strabismus/Q21/flip_crop_report.csv | 0.055 | 2d87e77328edcdecaf8e9eb8e13b0c689b50e75512d9bfe9741b18a3964d7ec5
strabismus | Q21 | metadata_or_report | experiments/binocular_visualization/hess_matched_results/strabismus/Q21/hess_match_metadata.json | 0.002 | 13b775d76ddca1d5d6e1d4302d50cc8c631579df12f6d2acaf20ff4f32615827
strabismus | Q21 | metadata_or_report | experiments/binocular_visualization/hess_matched_results/strabismus/Q21/hess_match_report.csv | 0.833 | 052ac5e8703587fbc52a08096ad2bf6991568a061396df12a2065f53b5e1d5f8
strabismus | Q22 | final_video_with_gaze_overlay | experiments/binocular_visualization/hess_matched_results/strabismus/Q22/stitched_frames_flipped_cropped_60fps_with_gaze_Q22_lead0p5s.mp4 | 15.511 | 84b8156f2217d21d82c6f3cf35502a470fc7f38d6b7134d4eace516af45b78ed
strabismus | Q22 | matrix_data | experiments/binocular_visualization/hess_matched_results/strabismus/Q22/matrices/hess_matched_homographies_Q22.npz | 2.257 | 6bf5df7cae952564f64cfe82aa41fafb3f69ad6210c26d7350466f6894f1ac4e
strabismus | Q22 | matrix_data | experiments/binocular_visualization/hess_matched_results/strabismus/Q22/matrices/hess_matched_homographies_Q22_before_health_second_initial_fix.npz | 2.256 | 0a6d895e754825919df3e318bf8d2d97e79282a0fe00bd6074f6ab13764eca42
strabismus | Q22 | metadata_or_report | experiments/binocular_visualization/hess_matched_results/strabismus/Q22/flip_crop_metadata.json | 0 | fee738a776856178f74f9093a56b45f36bd51d6c2cef8641701373b7d8a9a704
strabismus | Q22 | metadata_or_report | experiments/binocular_visualization/hess_matched_results/strabismus/Q22/flip_crop_report.csv | 0.055 | b1b828b11450ec89e0820776fbae5613398e1de69fec9a6ba3eff9299e571246
strabismus | Q22 | metadata_or_report | experiments/binocular_visualization/hess_matched_results/strabismus/Q22/hess_match_metadata.json | 0.002 | 70ff296bd6a884091d240d31cb7428be92ff3ff6631274de64e25bdb98990b3a
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

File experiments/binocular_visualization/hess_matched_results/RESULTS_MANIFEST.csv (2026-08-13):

cohort | subject | source_folder | result_folder | final_video | video_size_mb | data_files | notes
healthy_reference | health_second | D:\visualization2026\dowsample2_health_second | experiments/binocular_visualization/hess_matched_results/healthy_reference | stitched_frames_flipped_cropped_60fps.mp4 | 21.34 | 15 | Healthy binocular reference video for comparison.
strabismus | Q11 | D:\visualization2026\dowsample2_Q11_hess_matched | experiments/binocular_visualization/hess_matched_results/strabismus/Q11 | stitched_frames_flipped_cropped_60fps_with_gaze_Q11_lead0p5s.mp4 | 17.22 | 5 | Hess-matched strabismus simulation with gaze overlay lead 0.5 s.
strabismus | Q13 | D:\visualization2026\dowsample2_Q13_hess_matched | experiments/binocular_visualization/hess_matched_results/strabismus/Q13 | stitched_frames_flipped_cropped_60fps_with_gaze_Q13_lead0p5s.mp4 | 18.02 | 5 | Hess-matched strabismus simulation with gaze overlay lead 0.5 s.
strabismus | Q14 | D:\visualization2026\dowsample2_Q14_hess_matched | experiments/binocular_visualization/hess_matched_results/strabismus/Q14 | stitched_frames_flipped_cropped_60fps_with_gaze_Q14_lead0p5s.mp4 | 17.95 | 5 | Hess-matched strabismus simulation with gaze overlay lead 0.5 s.
strabismus | Q16 | D:\visualization2026\dowsample2_Q16_hess_matched | experiments/binocular_visualization/hess_matched_results/strabismus/Q16 | stitched_frames_flipped_cropped_60fps_with_gaze_Q16_lead0p5s.mp4 | 18.99 | 5 | Hess-matched strabismus simulation with gaze overlay lead 0.5 s.
strabismus | Q21 | D:\visualization2026\dowsample2_Q21_hess_matched | experiments/binocular_visualization/hess_matched_results/strabismus/Q21 | stitched_frames_flipped_cropped_60fps_with_gaze_Q21_lead0p5s.mp4 | 17.19 | 5 | Hess-matched strabismus simulation with gaze overlay lead 0.5 s.
strabismus | Q22 | D:\visualization2026\dowsample2_Q22_hess_matched | experiments/binocular_visualization/hess_matched_results/strabismus/Q22 | stitched_frames_flipped_cropped_60fps_with_gaze_Q22_lead0p5s.mp4 | 15.51 | 6 | Hess-matched strabismus simulation with gaze overlay lead 0.5 s.
strabismus | Q23 | D:\visualization2026\dowsample2_Q23_hess_matched | experiments/binocular_visualization/hess_matched_results/strabismus/Q23 | stitched_frames_flipped_cropped_60fps_with_gaze_Q23_lead0p5s.mp4 | 18.26 | 5 | Hess-matched strabismus simulation with gaze overlay lead 0.5 s.
strabismus | Q27 | D:\visualization2026\dowsample2_Q27_hess_matched | experiments/binocular_visualization/hess_matched_results/strabismus/Q27 | stitched_frames_flipped_cropped_60fps_with_gaze_Q27_lead0p5s.mp4 | 17.93 | 5 | Hess-matched strabismus simulation with gaze overlay lead 0.5 s.
strabismus | Q29 | D:\visualization2026\dowsample2_Q29_hess_matched | experiments/binocular_visualization/hess_matched_results/strabismus/Q29 | stitched_frames_flipped_cropped_60fps_with_gaze_Q29_lead0p5s.mp4 | 17.28 | 6 | Hess-matched strabismus simulation with gaze overlay lead 0.5 s.
strabismus | Q3 | D:\visualization2026\dowsample2_Q3_hess_matched | experiments/binocular_visualization/hess_matched_results/strabismus/Q3 | stitched_frames_flipped_cropped_60fps_with_gaze_Q3_lead0p5s.mp4 | 17.75 | 5 | Hess-matched strabismus simulation with gaze overlay lead 0.5 s.
strabismus | Q33 | D:\visualization2026\dowsample2_Q33_hess_matched | experiments/binocular_visualization/hess_matched_results/strabismus/Q33 | stitched_frames_flipped_cropped_60fps_with_gaze_Q33_lead0p5s.mp4 | 17.55 | 6 | Hess-matched strabismus simulation with gaze overlay lead 0.5 s.
strabismus | Q37 | D:\visualization2026\dowsample2_Q37_hess_matched | experiments/binocular_visualization/hess_matched_results/strabismus/Q37 | stitched_frames_flipped_cropped_60fps_with_gaze_Q37_lead0p5s.mp4 | 17.6 | 5 | Hess-matched strabismus simulation with gaze overlay lead 0.5 s.
strabismus | Q40 | D:\visualization2026\dowsample2_Q40_hess_matched | experiments/binocular_visualization/hess_matched_results/strabismus/Q40 | stitched_frames_flipped_cropped_60fps_with_gaze_Q40_lead0p5s.mp4 | 17.11 | 5 | Hess-matched strabismus simulation with gaze overlay lead 0.5 s.
strabismus | Q44 | D:\visualization2026\dowsample2_Q44_hess_matched | experiments/binocular_visualization/hess_matched_results/strabismus/Q44 | stitched_frames_flipped_cropped_60fps_with_gaze_Q44_lead0p5s.mp4 | 18.93 | 5 | Hess-matched strabismus simulation with gaze overlay lead 0.5 s.
strabismus | Q45 | D:\visualization2026\dowsample2_Q45_hess_matched | experiments/binocular_visualization/hess_matched_results/strabismus/Q45 | stitched_frames_flipped_cropped_60fps_with_gaze_Q45_lead0p5s.mp4 | 18.23 | 6 | Hess-matched strabismus simulation with gaze overlay lead 0.5 s.
strabismus | Q47 | D:\visualization2026\dowsample2_Q47_hess_matched | experiments/binocular_visualization/hess_matched_results/strabismus/Q47 | stitched_frames_flipped_cropped_60fps_with_gaze_Q47_lead0p5s.mp4 | 18.78 | 5 | Hess-matched strabismus simulation with gaze overlay lead 0.5 s.
strabismus | Q48 | D:\visualization2026\dowsample2_Q48_hess_matched | experiments/binocular_visualization/hess_matched_results/strabismus/Q48 | stitched_frames_flipped_cropped_60fps_with_gaze_Q48_lead0p5s.mp4 | 18.09 | 5 | Hess-matched strabismus simulation with gaze overlay lead 0.5 s.

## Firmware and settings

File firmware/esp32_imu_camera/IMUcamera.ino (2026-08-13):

#include <Arduino.h>
#include "esp_camera.h"
#include <Wire.h>
#include <WiFi.h>
#include <WebServer.h>

#define CAMERA_ROLE_EXTERNAL_WIFI 1
#define CAMERA_ROLE_HUB_AP 2
#define CAMERA_ROLE_CLIENT_TO_HUB 3
#define CAMERA_ROLE_AUTO_ESP_AP 4

#if __has_include("wifi_secrets.h")
#include "wifi_secrets.h"
#endif

#ifndef CAMERA_WIFI_ROLE
#define CAMERA_WIFI_ROLE CAMERA_ROLE_AUTO_ESP_AP
#endif

#ifndef WIFI_SSID
#define WIFI_SSID ""
#define WIFI_PASSWORD ""
#endif

#ifndef HUB_AP_SSID
#define HUB_AP_SSID "ESP32S3-CAM-NET"
#define HUB_AP_PASSWORD "esp32camera"
#endif

#ifndef HUB_CLIENT_STATIC_IP_LAST_OCTET
#define HUB_CLIENT_STATIC_IP_LAST_OCTET 200
#endif

// Aideepen/Keyestudio/Freenove-style ESP32-S3 CAM, same pinout as CAMERA_MODEL_ESP32S3_EYE.
// Arduino IDE target: ESP32S3 Dev Module
// Important Tools settings for this tested board:
//   Flash Size: 8MB
//   PSRAM: OPI PSRAM / Octal PSRAM
#define PWDN_GPIO_NUM  -1
#define RESET_GPIO_NUM -1

#define XCLK_GPIO_NUM  15
#define SIOD_GPIO_NUM   4
#define SIOC_GPIO_NUM   5

#define Y9_GPIO_NUM    16
#define Y8_GPIO_NUM    17
#define Y7_GPIO_NUM    18
#define Y6_GPIO_NUM    12
#define Y5_GPIO_NUM    10
#define Y4_GPIO_NUM     8
#define Y3_GPIO_NUM     9
#define Y2_GPIO_NUM    11

#define VSYNC_GPIO_NUM  6
#define HREF_GPIO_NUM   7
#define PCLK_GPIO_NUM  13

// BNO055 IMU I2C pins. These do not conflict with the camera pins above.
static const int IMU_SDA_PIN = 1;
static const int IMU_SCL_PIN = 2;

static const uint8_t BNO055_ADDR = 0x28;  // Change to 0x29 if ADR is high.

static const uint8_t BNO055_CHIP_ID_ADDR = 0x00;
static const uint8_t BNO055_GYRO_DATA_X_LSB_ADDR = 0x14;
static const uint8_t BNO055_EULER_H_LSB_ADDR = 0x1A;
static const uint8_t BNO055_LINEAR_ACCEL_DATA_X_LSB_ADDR = 0x28;
static const uint8_t BNO055_OPR_MODE_ADDR = 0x3D;
static const uint8_t BNO055_PWR_MODE_ADDR = 0x3E;
static const uint8_t BNO055_SYS_TRIGGER_ADDR = 0x3F;
static const uint8_t BNO055_UNIT_SEL_ADDR = 0x3B;

static const uint8_t CONFIGMODE = 0x00;
static const uint8_t NDOF_MODE = 0x0C;
static const uint8_t NORMAL_POWER_MODE = 0x00;

static const uint32_t SERIAL_BAUD = 921600;
static const unsigned long IMU_INTERVAL_MS = 50;  // 20 Hz, matching IMUtest.
static const uint32_t WIFI_CONNECT_TIMEOUT_MS = 15000;
static const uint32_t HUB_SCAN_DELAY_MIN_MS = 1200;
static const uint32_t HUB_SCAN_DELAY_SPREAD_MS = 6000;
static const char *AP_SSID_PREFIX = "ESP32S3-CAM";
static const char *AP_PASSWORD = "esp32camera";

// Stability-first defaults. After QVGA is stable, use /set?size=VGA&quality=12.
static const framesize_t START_FRAME_SIZE = FRAMESIZE_QVGA;
static const int START_JPEG_QUALITY = 15;
static const uint16_t STREAM_DELAY_MS = 20;
static const size_t STREAM_CHUNK_SIZE = 1460;

WebServer server(80);

bool softApMode = false;
bool cameraReady = false;
framesize_t currentFrameSize = START_FRAME_SIZE;
int currentJpegQuality = START_JPEG_QUALITY;
uint32_t totalFrames = 0;
uint32_t failedFrames = 0;
String deviceSuffix;
String deviceHostname;
String softApSsid;
String activeNetworkRole = "unknown";

bool imuReady = false;
unsigned long lastIMURead = 0;
uint32_t imuReadCount = 0;
uint32_t imuReadErrors = 0;

bool hasYawOffset = false;
float yawOffset = 0.0f;

bool hasLastEuler = false;
bool hasLastEulerRate = false;
unsigned long lastEulerMicros = 0;
float lastYaw = 0.0f;
float lastPitch = 0.0f;
float lastRoll = 0.0f;
float lastYawRate = 0.0f;
float lastPitchRate = 0.0f;
float lastRollRate = 0.0f;

bool hasLatestIMU = false;
unsigned long latestIMUMillis = 0;
float latestYaw = 0.0f;
float latestRoll = 0.0f;
float latestPitch = 0.0f;
float latestYawRate = 0.0f;
float latestPitchRate = 0.0f;
float latestRollRate = 0.0f;
float latestYawAccel = 0.0f;
float latestPitchAccel = 0.0f;
float latestRollAccel = 0.0f;
float latestLinAccX = 0.0f;
float latestLinAccY = 0.0f;
float latestLinAccZ = 0.0f;
float latestGyroX = 0.0f;
float latestGyroY = 0.0f;
float latestGyroZ = 0.0f;

struct FrameSizeOption {
  const char *name;
  framesize_t value;
};

static const FrameSizeOption FRAME_SIZES[] = {
  {"QQVGA", FRAMESIZE_QQVGA},
  {"QVGA", FRAMESIZE_QVGA},
  {"VGA", FRAMESIZE_VGA},
  {"SVGA", FRAMESIZE_SVGA},
};

const char *frameSizeName(framesize_t value) {
  for (const FrameSizeOption &option : FRAME_SIZES) {
    if (option.value == value) {
      return option.name;
    }
  }
  return "UNKNOWN";
}

IPAddress cameraIp() {
  return softApMode ? WiFi.softAPIP() : WiFi.localIP();
}

String makeDeviceSuffix() {
  uint64_t mac = ESP.getEfuseMac();
  char suffix[7];
  snprintf(suffix, sizeof(suffix), "%06X", (uint32_t)(mac & 0xFFFFFF));
  return String(suffix);
}

void initDeviceIdentity() {
  deviceSuffix = makeDeviceSuffix();
  deviceHostname = "esp32s3-cam-" + deviceSuffix;
  softApSsid = String(AP_SSID_PREFIX) + "-" + deviceSuffix;
}

bool writeReg(uint8_t reg, uint8_t value) {
  Wire.beginTransmission(BNO055_ADDR);
  Wire.write(reg);
  Wire.write(value);
  return Wire.endTransmission() == 0;
}

bool readRegs(uint8_t reg, uint8_t *buffer, uint8_t len) {
  Wire.beginTransmission(BNO055_ADDR);
  Wire.write(reg);
  if (Wire.endTransmission(false) != 0) {
    return false;
  }

  uint8_t count = Wire.requestFrom(BNO055_ADDR, len);
  if (count != len) {
    return false;
  }

  for (uint8_t i = 0; i < len; i++) {
    buffer[i] = Wire.read();
  }
  return true;
}

int16_t readS16LE(uint8_t *buf, int idx) {
  return (int16_t)((buf[idx + 1] << 8) | buf[idx]);
}

float normalizeAngleDelta(float deltaDeg) {
  while (deltaDeg > 180.0f) {
    deltaDeg -= 360.0f;
  }
  while (deltaDeg <= -180.0f) {
    deltaDeg += 360.0f;
  }
  return deltaDeg;
}

void appendIMUCsv(String &text) {
  text += "IMU,";
  text += String(latestYaw, 2);
  text += ",";
  text += String(latestRoll, 2);
  text += ",";
  text += String(latestPitch, 2);
  text += ",";
  text += String(latestYawRate, 3);
  text += ",";
  text += String(latestPitchRate, 3);
  text += ",";
  text += String(latestRollRate, 3);
  text += ",";
  text += String(latestYawAccel, 3);
  text += ",";
  text += String(latestPitchAccel, 3);
  text += ",";
  text += String(latestRollAccel, 3);
  text += ",";
  text += String(latestLinAccX, 3);
  text += ",";
  text += String(latestLinAccY, 3);
  text += ",";
  text += String(latestLinAccZ, 3);
  text += ",";
  text += String(latestGyroX, 3);
  text += ",";
  text += String(latestGyroY, 3);
  text += ",";
  text += String(latestGyroZ, 3);
  text += "\n";
}

void printLatestIMUCsv() {
  Serial.print("IMU,");
  Serial.print(latestYaw, 2);
  Serial.print(",");
  Serial.print(latestRoll, 2);
  Serial.print(",");
  Serial.print(latestPitch, 2);
  Serial.print(",");
  Serial.print(latestYawRate, 3);
  Serial.print(",");
  Serial.print(latestPitchRate, 3);
  Serial.print(",");
  Serial.print(latestRollRate, 3);
  Serial.print(",");
  Serial.print(latestYawAccel, 3);
  Serial.print(",");
  Serial.print(latestPitchAccel, 3);
  Serial.print(",");
  Serial.print(latestRollAccel, 3);
  Serial.print(",");
  Serial.print(latestLinAccX, 3);
  Serial.print(",");
  Serial.print(latestLinAccY, 3);
  Serial.print(",");
  Serial.print(latestLinAccZ, 3);
  Serial.print(",");
  Serial.print(latestGyroX, 3);
  Serial.print(",");
  Serial.print(latestGyroY, 3);
  Serial.print(",");
  Serial.println(latestGyroZ, 3);
}

bool initBNO055() {
  Wire.begin(IMU_SDA_PIN, IMU_SCL_PIN);
  Wire.setClock(100000);
  delay(50);

  uint8_t chipId = 0;
  if (!readRegs(BNO055_CHIP_ID_ADDR, &chipId, 1)) {
    Serial.println("WARN Failed to read BNO055 chip ID; camera will continue without IMU.");
    return false;
  }

  Serial.print("BNO055 Chip ID = 0x");
  Serial.println(chipId, HEX);

  if (chipId != 0xA0) {
    Serial.println("WARN BNO055 chip ID is not 0xA0; camera will continue without IMU.");
    return false;
  }

  if (!writeReg(BNO055_OPR_MODE_ADDR, CONFIGMODE)) return false;
  delay(50);

  if (!writeReg(BNO055_PWR_MODE_ADDR, NORMAL_POWER_MODE)) return false;
  delay(10);

  // 0x00: Euler angle deg, gyro deg/s, acceleration m/s^2.
  if (!writeReg(BNO055_UNIT_SEL_ADDR, 0x00)) return false;
  delay(10);

  if (!writeReg(BNO055_SYS_TRIGGER_ADDR, 0x00)) return false;
  delay(10);

  if (!writeReg(BNO055_OPR_MODE_ADDR, NDOF_MODE)) return false;
  delay(200);

  return true;
}

void readAndPrintIMU() {
  uint8_t eulerData[6];
  uint8_t gyroData[6];
  uint8_t linearAccelData[6];

  bool okEuler = readRegs(BNO055_EULER_H_LSB_ADDR, eulerData, 6);
  bool okGyro = readRegs(BNO055_GYRO_DATA_X_LSB_ADDR, gyroData, 6);
  bool okLinearAccel = readRegs(BNO055_LINEAR_ACCEL_DATA_X_LSB_ADDR, linearAccelData, 6);

  if (!okEuler || !okGyro || !okLinearAccel) {
    imuReadErrors++;
    Serial.println("READ_ERROR");
    return;
  }

  int16_t headingRaw = readS16LE(eulerData, 0);
  int16_t rollRaw = readS16LE(eulerData, 2);
  int16_t pitchRaw = readS16LE(eulerData, 4);

  int16_t gyroXRaw = readS16LE(gyroData, 0);
  int16_t gyroYRaw = readS16LE(gyroData, 2);
  int16_t gyroZRaw = readS16LE(gyroData, 4);

  int16_t linAccXRaw = readS16LE(linearAccelData, 0);
  int16_t linAccYRaw = readS16LE(linearAccelData, 2);
  int16_t linAccZRaw = readS16LE(linearAccelData, 4);

  float yaw = headingRaw / 16.0f;
  float roll = rollRaw / 16.0f;
  float pitch = pitchRaw / 16.0f;

  if (!hasYawOffset) {
    yawOffset = yaw;
    hasYawOffset = true;
  }
  yaw = normalizeAngleDelta(yaw - yawOffset);

  float gyroX = gyroXRaw / 16.0f;
  float gyroY = gyroYRaw / 16.0f;
  float gyroZ = gyroZRaw / 16.0f;

  float linAccX = linAccXRaw / 100.0f;
  float linAccY = linAccYRaw / 100.0f;
  float linAccZ = linAccZRaw / 100.0f;

  unsigned long nowMicros = micros();
  float yawRate = 0.0f;
  float pitchRate = 0.0f;
  float rollRate = 0.0f;
  float yawAccel = 0.0f;
  float pitchAccel = 0.0f;
  float rollAccel = 0.0f;
  bool computedEulerRate = false;

  if (hasLastEuler) {
    float dt = (nowMicros - lastEulerMicros) / 1000000.0f;
    if (dt > 0.000001f) {
      yawRate = normalizeAngleDelta(yaw - lastYaw) / dt;
      pitchRate = (pitch - lastPitch) / dt;
      rollRate = normalizeAngleDelta(roll - lastRoll) / dt;
      computedEulerRate = true;

      if (hasLastEulerRate) {
        yawAccel = (yawRate - lastYawRate) / dt;
        pitchAccel = (pitchRate - lastPitchRate) / dt;
        rollAccel = (rollRate - lastRollRate) / dt;
      }
    }
  }

  lastYaw = yaw;
  lastPitch = pitch;
  lastRoll = roll;
  lastYawRate = yawRate;
  lastPitchRate = pitchRate;
  lastRollRate = rollRate;
  lastEulerMicros = nowMicros;
  hasLastEuler = true;
  hasLastEulerRate = computedEulerRate;

  latestYaw = yaw;
  latestRoll = roll;
  latestPitch = pitch;
  latestYawRate = yawRate;
  latestPitchRate = pitchRate;
  latestRollRate = rollRate;
  latestYawAccel = yawAccel;
  latestPitchAccel = pitchAccel;
  latestRollAccel = rollAccel;
  latestLinAccX = linAccX;
  latestLinAccY = linAccY;
  latestLinAccZ = linAccZ;
  latestGyroX = gyroX;
  latestGyroY = gyroY;
  latestGyroZ = gyroZ;
  latestIMUMillis = millis();
  hasLatestIMU = true;
  imuReadCount++;

  printLatestIMUCsv();
}

void serviceIMU() {
  if (!imuReady) {
    return;
  }

  unsigned long now = millis();
  if (now - lastIMURead >= IMU_INTERVAL_MS) {
    lastIMURead = now;
    readAndPrintIMU();
  }
}

void delayWithIMU(uint32_t ms) {
  uint32_t start = millis();
  while (millis() - start < ms) {
    serviceIMU();
    delay(2);
  }
}

bool writeClientAll(WiFiClient &client, const uint8_t *buffer, size_t length) {
  size_t offset = 0;
  uint16_t noProgressCount = 0;

  while (offset < length && client.connected()) {
    size_t remaining = length - offset;
    size_t chunk = remaining < STREAM_CHUNK_SIZE ? remaining : STREAM_CHUNK_SIZE;
    size_t written = client.write(buffer + offset, chunk);

    if (written == 0) {
      noProgressCount++;
      if (noProgressCount > 200) {
        return false;
      }
      serviceIMU();
      delay(1);
      continue;
    }

    noProgressCount = 0;
    offset += written;
    serviceIMU();
    delay(0);
  }

  return offset == length;
}

void appendStatus(String &text) {
  text += "ready=yes\n";
  text += "ip=" + cameraIp().toString() + "\n";
  text += "mode=" + String(softApMode ? "soft_ap" : "wifi_sta") + "\n";
  text += "network_role=" + activeNetworkRole + "\n";
  text += "device=" + deviceHostname + "\n";
  text += "mac_suffix=" + deviceSuffix + "\n";
  text += "camera_ready=" + String(cameraReady ? "yes" : "no") + "\n";
  text += "stream=http://" + cameraIp().toString() + "/stream\n";
  text += "capture=http://" + cameraIp().toString() + "/capture\n";
  text += "psram_found=" + String(psramFound() ? "yes" : "no") + "\n";
  text += "psram_size=" + String((uint32_t)ESP.getPsramSize()) + "\n";
  text += "free_psram=" + String((uint32_t)ESP.getFreePsram()) + "\n";
  text += "heap_size=" + String((uint32_t)ESP.getHeapSize()) + "\n";
  text += "free_heap=" + String((uint32_t)ESP.getFreeHeap()) + "\n";
  text += "frame_size=" + String(frameSizeName(currentFrameSize)) + "\n";
  text += "jpeg_quality=" + String(currentJpegQuality) + "\n";
  text += "total_frames=" + String(totalFrames) + "\n";
  text += "failed_frames=" + String(failedFrames) + "\n";
  text += "imu_ready=" + String(imuReady ? "yes" : "no") + "\n";
  text += "imu_samples=" + String(imuReadCount) + "\n";
  text += "imu_read_errors=" + String(imuReadErrors) + "\n";
  if (hasLatestIMU) {
    text += "imu_age_ms=" + String((uint32_t)(millis() - latestIMUMillis)) + "\n";
    text += "imu_yaw=" + String(latestYaw, 2) + "\n";
    text += "imu_roll=" + String(latestRoll, 2) + "\n";
    text += "imu_pitch=" + String(latestPitch, 2) + "\n";
    text += "imu_yaw_rate=" + String(latestYawRate, 3) + "\n";
    text += "imu_pitch_rate=" + String(latestPitchRate, 3) + "\n";
    text += "imu_roll_rate=" + String(latestRollRate, 3) + "\n";
  }
}

void handleRoot() {
  String html;
  html.reserve(1800);
  html += "<!doctype html><html><head>";
  html += "<meta name=\"viewport\" content=\"width=device-width,initial-scale=1\">";
  html += "<title>ESP32-S3 CAM Test</title>";
  html += "<style>body{font-family:Arial,sans-serif;margin:20px;background:#101418;color:#f4f7fb}";
  html += "a{color:#6ee7ff}img{max-width:100%;height:auto;border:1px solid #3a4652}";
  html += "code{background:#1b232c;padding:2px 5px;border-radius:4px}</style>";
  html += "</head><body>";
  html += "<h2>ESP32-S3 CAM Test</h2>";
  html += "<p>Device: <code>";
  html += deviceHostname;
  html += "</code></p>";
  html += "<p>Role: <code>";
  html += activeNetworkRole;
  html += "</code></p>";
  html += "<p><code>http://";
  html += cameraIp().toString();
  html += "</code></p>";
  html += "<p><a href=\"/capture\" target=\"_blank\">capture</a> ";
  html += "<a href=\"/stream\" target=\"_blank\">stream</a> ";
  html += "<a href=\"/status\" target=\"_blank\">status</a> ";
  html += "<a href=\"/imu\" target=\"_blank\">imu</a></p>";
  html += "<p>";
  html += "<a href=\"/set?size=QVGA&quality=15\">QVGA</a> ";
  html += "<a href=\"/set?size=VGA&quality=12\">VGA</a> ";
  html += "<a href=\"/set?size=SVGA&quality=14\">SVGA</a>";
  html += "</p>";
  if (cameraReady) {
    html += "<img src=\"/stream\">";
  } else {
    html += "<p><strong>Camera is not available.</strong> IMU serial output and <a href=\"/imu\" target=\"_blank\">/imu</a> are still running.</p>";
  }
  html += "</body></html>";
  server.send(200, "text/html", html);
}

void handleStatus() {
  String status;
  status.reserve(1100);
  appendStatus(status);
  server.send(200, "text/plain", status);
}

void handleIMU() {
  String response;
  response.reserve(450);
  response += "ready=" + String(imuReady ? "yes" : "no") + "\n";
  response += "samples=" + String(imuReadCount) + "\n";
  response += "read_errors=" + String(imuReadErrors) + "\n";

  if (!hasLatestIMU) {
    response += "latest=none\n";
    server.send(imuReady ? 200 : 503, "text/plain", response);
    return;
  }

  response += "age_ms=" + String((uint32_t)(millis() - latestIMUMillis)) + "\n";
  response += "format=IMU,yaw,roll,pitch,yaw_rate,pitch_rate,roll_rate,yaw_accel,pitch_accel,roll_accel,linacc_x,linacc_y,linacc_z,gyro_x,gyro_y,gyro_z\n";
  appendIMUCsv(response);
  server.send(200, "text/plain", response);
}

void handleSet() {
  if (!cameraReady) {
    server.send(503, "text/plain", "camera is not available; IMU is still running");
    return;
  }

  sensor_t *sensor = esp_camera_sensor_get();
  if (!sensor) {
    server.send(500, "text/plain", "camera sensor is not available");
    return;
  }

  String response;
  response.reserve(300);

  if (server.hasArg("size")) {
    String requested = server.arg("size");
    requested.toUpperCase();

    bool found = false;
    for (const FrameSizeOption &option : FRAME_SIZES) {
      if (requested == option.name) {
        int rc = sensor->set_framesize(sensor, option.value);
        if (rc == 0) {
          currentFrameSize = option.value;
          response += "frame_size=" + String(option.name) + "\n";
        } else {
          response += "frame_size_error=" + String(rc) + "\n";
        }
        found = true;
        break;
      }
    }

    if (!found) {
      response += "frame_size_error=unknown size; use QQVGA,QVGA,VGA,SVGA\n";
    }
  }

  if (server.hasArg("quality")) {
    int quality = server.arg("quality").toInt();
    if (quality >= 4 && quality <= 30) {
      int rc = sensor->set_quality(sensor, quality);
      if (rc == 0) {
        currentJpegQuality = quality;
        response += "jpeg_quality=" + String(quality) + "\n";
      } else {
        response += "jpeg_quality_error=" + String(rc) + "\n";
      }
    } else {
      response += "jpeg_quality_error=use 4..30, higher number is lower quality/faster\n";
    }
  }

  if (response.length() == 0) {
    response = "nothing changed; try /set?size=VGA&quality=12\n";
  }

  response += "\n";
  appendStatus(response);
  server.send(200, "text/plain", response);
}

void handleCapture() {
  if (!cameraReady) {
    server.send(503, "text/plain", "camera is not available; IMU is still running");
    return;
  }

  camera_fb_t *fb = esp_camera_fb_get();
  if (!fb) {
    failedFrames++;
    server.send(500, "text/plain", "Camera capture failed");
    return;
  }

  totalFrames++;
  WiFiClient client = server.client();
  client.printf(
    "HTTP/1.1 200 OK\r\n"
    "Content-Type: image/jpeg\r\n"
    "Content-Length: %u\r\n"
    "Cache-Control: no-store\r\n"
    "Connection: close\r\n"
    "\r\n",
    (unsigned int)fb->len
  );
  client.write(fb->buf, fb->len);
  client.flush();

  esp_camera_fb_return(fb);
  client.stop();
}

void handleStream() {
  if (!cameraReady) {
    server.send(503, "text/plain", "camera is not available; IMU is still running");
    return;
  }

  WiFiClient client = server.client();
  client.setNoDelay(true);

  client.print("HTTP/1.1 200 OK\r\n");
  client.print("Content-Type: multipart/x-mixed-replace; boundary=frame\r\n");
  client.print("Cache-Control: no-cache\r\n");
  client.print("Connection: close\r\n\r\n");

  uint32_t windowStartMs = millis();
  uint32_t windowFrames = 0;
  uint32_t windowBytes = 0;

  while (client.connected()) {
    serviceIMU();

    camera_fb_t *fb = esp_camera_fb_get();
    if (!fb) {
      failedFrames++;
      Serial.println("Camera capture failed");
      delayWithIMU(50);
      continue;
    }

    totalFrames++;
    windowFrames++;
    windowBytes += fb->len;

    client.print("--frame\r\n");
    client.print("Content-Type: image/jpeg\r\n");
    client.printf("Content-Length: %u\r\n\r\n", (unsigned int)fb->len);
    bool ok = writeClientAll(client, fb->buf, fb->len);
    client.print("\r\n");

    esp_camera_fb_return(fb);

    if (!ok) {
      break;
    }

    uint32_t now = millis();
    if (now - windowStartMs >= 1000) {
      float seconds = (now - windowStartMs) / 1000.0f;
      float fps = windowFrames / seconds;
      uint32_t avgBytes = windowFrames > 0 ? windowBytes / windowFrames : 0;
      Serial.printf(
        "Stream: %.1f fps, avg=%u bytes, size=%s, q=%d, free_heap=%u, free_psram=%u\n",
        fps,
        (unsigned int)avgBytes,
        frameSizeName(currentFrameSize),
        currentJpegQuality,
        (unsigned int)ESP.getFreeHeap(),
        (unsigned int)ESP.getFreePsram()
      );
      windowStartMs = now;
      windowFrames = 0;
      windowBytes = 0;
    }

    delayWithIMU(STREAM_DELAY_MS);
  }

  client.stop();
  Serial.println("Stream client disconnected");
}
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
void loop() {
  serviceIMU();
  server.handleClient();
}

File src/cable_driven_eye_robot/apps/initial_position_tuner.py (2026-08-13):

from __future__ import annotations

import argparse
import time
from dataclasses import replace

try:
    import msvcrt
except ImportError:  # pragma: no cover
    msvcrt = None

from ..config import DynamixelConfig, ProfileConfig, RobotConfig
from ..hardware.dynamixel import DynamixelController
from ..input_devices.joystick import JoystickReader
from ..math_utils import apply_deadband, clamp


CROSS_BTN = 0
CIRCLE_BTN = 1
SQUARE_BTN = 2
TRIANGLE_BTN = 3
L1_BTN = 9
R1_BTN = 10
LEFT_STICK_CLICK_BTN = 7
DPAD_UP_BTN = 11
DPAD_DOWN_BTN = 12
DPAD_LEFT_BTN = 13
DPAD_RIGHT_BTN = 14
L2_AXIS = 4
R2_AXIS = 5
RIGHT_Y_AXIS = 3
DPAD_HAT_INDEX = 0
TRIGGER_PRESS_THRESHOLD = 0.5


BUTTON_MOTOR_MAP = {
    CIRCLE_BTN: 1,
    SQUARE_BTN: 2,
    TRIANGLE_BTN: 3,
    CROSS_BTN: 4,
    R1_BTN: 5,
    L1_BTN: 11,
    DPAD_RIGHT_BTN: 7,
    DPAD_LEFT_BTN: 8,
    DPAD_UP_BTN: 9,
    DPAD_DOWN_BTN: 10,
}

TRIGGER_MOTOR_MAP = {
    R2_AXIS: 6,
    L2_AXIS: 12,
}

HAT_MOTOR_MAP = {
    (1, 0): 7,
    (-1, 0): 8,
    (0, 1): 9,
    (0, -1): 10,
}

MOTOR_DIRECTIONS = {
    1: 1,
    2: 1,
    3: -1,
    4: -1,
    5: -1,
    6: 1,
    7: -1,
    8: -1,
    9: 1,
    10: 1,
    11: 1,
    12: -1,
}


def parse_args() -> argparse.Namespace:
    parser = argparse.ArgumentParser(description="Manual neutral-position tuner for all 12 Dynamixel motors.")
    parser.add_argument("--dxl-port", default="COM12")
    parser.add_argument("--dxl-baud", type=int, default=1_000_000)
    parser.add_argument("--max-jog-ticks-per-sec", type=float, default=700.0)
    parser.add_argument("--write-period-s", type=float, default=0.02)
    parser.add_argument("--deadband", type=float, default=0.08)
    return parser.parse_args()


def build_config(args: argparse.Namespace) -> RobotConfig:
    base = RobotConfig()
    return replace(
        base,
        dynamixel=replace(base.dynamixel, device_name=args.dxl_port, baudrate=args.dxl_baud),
    )


def print_positions(label: str, positions: list[float]) -> None:
    print(f"{label}: [{', '.join(str(int(value)) for value in positions)}]")


def keyboard_stop_requested() -> bool:
    if msvcrt is None:
        return False
    if msvcrt.kbhit():
        msvcrt.getch()
        return True
    return False


def run() -> int:
    args = parse_args()
    config = build_config(args)
    joystick = JoystickReader(config.joystick)
    controller = DynamixelController(config.dynamixel, config.profile)

    try:
        joystick.open()
        print(f"Detected joystick: {joystick.name}")
        controller.open()
        goal_positions = [float(value) for value in controller.initial_positions]
        last_written_positions = [int(round(value)) for value in goal_positions]
        print_positions("Initial present positions", goal_positions)

        print("Select motor, then push right stick up/down to jog.")
        print("Circle=1, Square=2, Triangle=3, Cross=4, R1=5, R2=6")
        print("D-pad Right=7, Left=8, Up=9, Down=10, L1=11, L2=12")
        print("Click left stick (L3) to finish and print positions.")

        selected_motor = 1
        previous_buttons = {button: joystick.safe_get_button(button) for button in BUTTON_MOTOR_MAP}
        previous_triggers = {
            axis: joystick.safe_get_axis(axis) > TRIGGER_PRESS_THRESHOLD
            for axis in TRIGGER_MOTOR_MAP
        }
        previous_hat = joystick.safe_get_hat(DPAD_HAT_INDEX)
        previous_finish = joystick.safe_get_button(LEFT_STICK_CLICK_BTN)
        last_loop = time.monotonic()
        last_write = 0.0
        last_status = 0.0

        while True:
            joystick.pump()
            now = time.monotonic()
            dt = clamp(now - last_loop, 0.0, 0.05)
            last_loop = now

            finish_now = joystick.safe_get_button(LEFT_STICK_CLICK_BTN)
            if finish_now and not previous_finish:
                print("Calibration finished by L3.")
                break
            previous_finish = finish_now

            if keyboard_stop_requested():
                print("Keyboard stop requested.")
                break

            for button, motor_id in BUTTON_MOTOR_MAP.items():
                pressed = joystick.safe_get_button(button)
                if pressed and not previous_buttons.get(button, False):
                    selected_motor = motor_id
                    goal_positions[motor_id - 1] = float(controller.read_single_present_position(motor_id))
                    print(f"Selected motor: ID {selected_motor}")
                previous_buttons[button] = pressed

            for axis, motor_id in TRIGGER_MOTOR_MAP.items():
                pressed = joystick.safe_get_axis(axis) > TRIGGER_PRESS_THRESHOLD
                if pressed and not previous_triggers.get(axis, False):
                    selected_motor = motor_id
                    goal_positions[motor_id - 1] = float(controller.read_single_present_position(motor_id))
                    print(f"Selected motor: ID {selected_motor}")
                previous_triggers[axis] = pressed

            hat = joystick.safe_get_hat(DPAD_HAT_INDEX)
            if hat != previous_hat:
                if hat in HAT_MOTOR_MAP:
                    selected_motor = HAT_MOTOR_MAP[hat]
                    goal_positions[selected_motor - 1] = float(controller.read_single_present_position(selected_motor))
                    print(f"Selected motor: ID {selected_motor}")
                previous_hat = hat

            stick_up = -joystick.safe_get_axis(RIGHT_Y_AXIS)
            stick_up = apply_deadband(stick_up, args.deadband)
            if stick_up != 0.0:
                index = selected_motor - 1
                direction = MOTOR_DIRECTIONS[selected_motor]
                goal_positions[index] += stick_up * direction * args.max_jog_ticks_per_sec * dt
                target_position = int(round(goal_positions[index]))
                if target_position != last_written_positions[index] and now - last_write >= args.write_period_s:
                    controller.set_goal_position(selected_motor, target_position)
                    last_written_positions[index] = target_position
                    last_write = now
                if now - last_status > 0.25:
                    print(f"ID {selected_motor} goal position: {target_position}")
                    last_status = now

            time.sleep(0.005)

        final_present = controller.read_all_present_positions()
        print_positions("Final goal positions", goal_positions)
        print_positions("Final present positions", final_present)
        return 0
    finally:
        try:
            if controller.is_open:
                controller.enable_torque(False)
        finally:
            controller.close()
            joystick.close()


if __name__ == "__main__":
    raise SystemExit(run())
